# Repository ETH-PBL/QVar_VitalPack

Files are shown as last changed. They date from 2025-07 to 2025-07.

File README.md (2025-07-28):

# QVAR 6-Channel VitalCore Backpack

## A high-precision 6-channel physiological sensing interface board for VitalCore

Federico Villani, ETH Zurich PBL, IIS, 2023

- Board documentation: [QVAR VitalCore Backpack](hardware/Documentation/QVAR_VC_FULL_DOC.PDF)

## Overview

The QVAR 6-Channel VitalCore Backpack (QVar VitalPack) features six QVar channels, providing a flexible system for testing and implementing various combinations of electrode positions. Its compact size 19.5 mm×16.5 mm and light weight (1.12 g) make it ideal for integration into wearable devices.

### Key Features

- **6 Independent differential or single-ended Channels**: Can use either ST1VAFE3BX or LIS2DUXS12. Depending on the configuration, the channels can be used for differential or single-ended measurements.
- **VitalCore Interface**: Native compatibility with [VitalCore v1.3](https://github.com/ETH-PBL/VitalCore)
- **Compact Form Factor**: Space-efficient (19.5 mm×16.5 mm) design for portable and wearable applications
- **Signal Conditioning**: Integrated filtering and ESD protection
- **Power Management**: Possibility to use either DC-DC converters on VitalCore or LDOs.

## System Architecture

### Core Components

- **6x QVAR Channels**: The 6 QVAR channels (QA1, QA2, QB1, QB2, QC1, QC2) are attached to 3 different I2C buses (I2CA, I2CB, I2CC) with 2 channels per bus. The I2C interface can be changed to SPI with a minor modification of the PCB.
- **Power Management**: The QVAR channels can be powered either by VitalCore VCORE voltage rails or by VA0 rail (VitalCore LDO) and VD2 rail (VitalCore DC-DC converter) output (by changing position of jumpers JP_A and JP_D). The QVAR channels attached to I2CB bus have to be powered by VCORE as the I2CB bus is always on on VitalCore.
- **Analog connections**: Differential measurement channels can be attached to the 1.27mm pitch connectors on signal Q1 and Q2 (Q1 and Q2 are the differential inputs for Plus and Minus electrodes of the QVAR chip). Single-ended channels can be attached either to Q1 or to the UMC connectors on the back-side of the PCB. 
- **Operating Voltage**: Nominal 1.8V, Compatible with VitalCore power rails

## Repository Structure

```text
6QChan_vitalcore_backpack/
├── PCB/                           # PCB design files
│   ├── main.SchDoc               # Main schematic
│   ├── Interface.SchDoc          # Interface circuitry
│   ├── QVAR.SchDoc              # Channel schematic
│   ├── QVAR6_VC_Backpack.PcbDoc # PCB layout
│   └── Libraries/               # Component libraries
├── Documentation/               # Project documentation
│   ├── QVAR_VC_assembly.PDF    # Assembly documentation
│   ├── QVAR_VC_schematics.PDF  # Schematic documentation
│   ├── QVAR_VC_FULL_DOC.PDF    # Complete design documentation
│   ├── BOM/                     # Bill of materials
│   └── Manufacturing/          # Manufacturing files
│       ├── Gerber/             # Gerber files for fabrication
│       └── NC Drill/           # Drill files
├── Draftsman/                  # Assembly and manufacturing drawings
├── settings/                   # Project configuration
└── 6QChan_vitalcore_backpack.PrjPcb  # Altium Designer project
```

## Technical Specifications

### PCB Specifications

- **Layer Count**: 6-layer
- **PCB Thickness**: 0.8mm 
- **Via Technology**: through-hole vias, filled and plated (Via in pad)
- **Surface Finish**: ENIG

## Getting Started

### Prerequisites

- Altium Designer (recommended version 20.0 or later)

### Viewing the Design Files

1. **Open the project**:

   ```bash
   Open 6QChan_vitalcore_backpack.PrjPcb in Altium Designer
   ```

2. **Navigate the design**:
   - `main.SchDoc`: System-level connections and interfaces
   - `Interface.SchDoc`: VitalCore interface circuitry
   - `QVAR.SchDoc`: Individual channel design (hierarchical)
   - `QVAR6_VC_Backpack.PcbDoc`: Complete PCB layout

3. **Generate documentation**:
   - Use the OutJob file in `settings/QVAR_VC_Backpack.OutJob`
   - Generate PDFs, Gerber files, and BOMs as needed

## Manufacturing and Assembly

### PCB Fabrication

Complete manufacturing data is provided in the `hardware/Documentation/Manufacturing/` folder:

- **Gerber Files**: Complete layer stackup and routing
- **Drill Files**: Via and mounting hole specifications

## Documentation

- **Schematics**: Complete electrical schematics (`QVAR_VC_schematics.PDF`)
- **Assembly Guide**: Assembly instructions and component placement (`QVAR_VC_assembly.PDF`)
- **Complete Documentation**: Full design package (`QVAR_VC_FULL_DOC.PDF`)
- **Manufacturing Files**: Fabrication and assembly data packages

Access all documentation in the `Documentation/` folder.

## Usage

### Channel Configuration

- Each QVAR channel can be independently configured
- Proper grounding and shielding essential for biomedical applications
- Reference electrode connections for differential measurements

## Publications

If you use the QVAR 6-Channel VitalCore Backpack in an academic or industrial context, please cite the relevant publications:

```bibtex
TODO ADD PUBLICATION
```

## Contributing

This is an open hardware project. Contributions are welcome in the form of:

- **Design Improvements**: Enhanced performance and optimization
- **Documentation Enhancements**: Better assembly guides and specifications
- **Bug Reports**: Issue identification and resolution

## License

This project is released under an open hardware license:

- **Hardware Design Files**: Solderpad v0.51 (SHL-0.51) (see LICENSE)
- **Documentation**: Creative Commons Attribution 4.0 International License (CC-BY-4.0)

## Contact and Support

For technical questions or collaboration inquiries:

- **Primary Contact**: Federico Villani ([villanif@ethz.ch](mailto:villanif@ethz.ch))
- **Organization**: PBL, IIS - ETH Zurich

## Version History

- **Version 1.0**: Initial release 
  
---

## Limitation of Liability

In no event and under no legal theory, whether in tort (including negligence), contract, or otherwise, unless required by applicable law (such as deliberate and grossly negligent acts) or agreed to in writing, shall any Contributor be liable to You for damages, including any direct, indirect, special, incidental, or consequential damages of any character arising as a result of this License or out of the use or inability to use the Work (including but not limited to damages for loss of goodwill, work stoppage, computer failure or malfunction, or any and all other commercial damages or losses), even if such Contributor has been advised of the possibility of such damages.

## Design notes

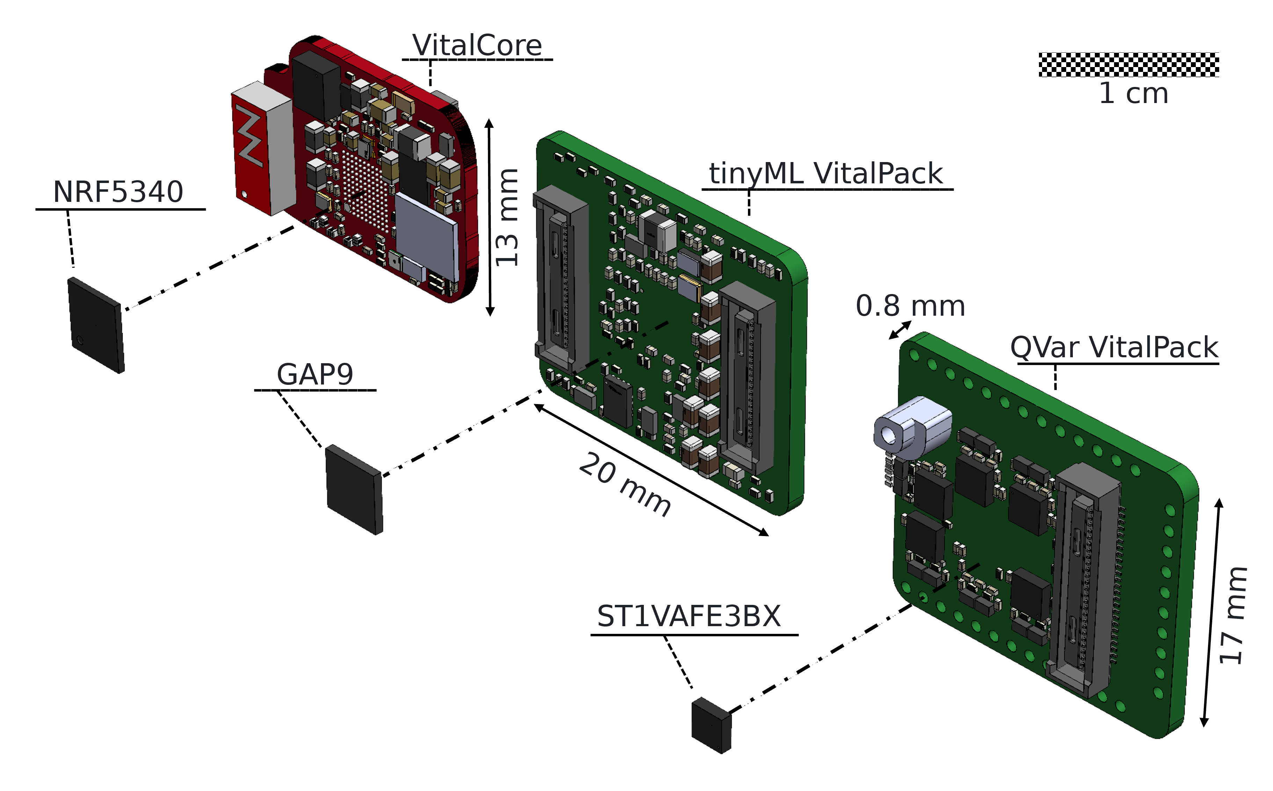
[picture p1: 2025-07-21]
assets/Electronics_3D.png

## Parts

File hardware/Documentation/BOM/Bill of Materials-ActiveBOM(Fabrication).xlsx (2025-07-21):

Line # | Name | Description | Designator | Footprint | LibRef | Supplier 1 | Supplier Part Number 1 | Quantity
1 | 0R | JMP 0201 3W | C1_QA1, C1_QA2, C1_QB1, C1_QB2, C1_QC1, C1_QC2, C2_QA1, C2_QA2, C2_QB1, C2_QB2, C2_QC1, C2_QC2 | RES_0201 | R_0201_0R_short_cap | Mouser | 667-ERJ-1GN0R00C | 12
1 | JMP | JMP 0201 3W | JP_A, JP_D | JMP_0201_3way | JMP_0201_3w | Mouser | 667-ERJ-1GN0R00C | 2
2 | 4.7k | R 4.7K 1% 50mW 0201 | R1_QA1, R1_QA2, R1_QB1, R1_QB2, R1_QC1, R1_QC2, R2_QA1, R2_QA2, R2_QB1, R2_QB2, R2_QC1, R2_QC2 | RES_0201 | R_0201_4.7K | Mouser | 667-ERJ-1GNF4701C | 12
3 | 100 nF | CAP CER 0.1UF 25V X5R 0201 | C5_QA1, C5_QA2, C5_QB1, C5_QB2, C5_QC1, C5_QC2, C6_QA1, C6_QA2, C6_QB1, C6_QB2, C6_QC1, C6_QC2 | CAP_0201 | CAP_0201_100n_10V | Mouser | 81-GRM33R6YA104ME14D | 12
4 | 110pF | CAP CER 110PF 50V C0G 0201 | CG1_QA1, CG1_QA2, CG1_QB1, CG1_QB2, CG1_QC1, CG1_QC2, CG2_QA1, CG2_QA2, CG2_QB1, CG2_QB2, CG2_QC1, CG2_QC2 | CAP_0201 | CAP_0201_110p_50V | Mouser | 81-GRM0335C1H111JA1D | 12
5 | 1µF | CAP CER 1UF 10V X6S | C4_QA1, C4_QA2, C4_QB1, C4_QB2, C4_QC1, C4_QC2, C7, C8, C9 | CAP_0201 | CAP_0201_1u_10V | Mouser | 81-GRM033C81A105ME5D | 9
6 | TPD1E01B04DPYRQ1 | TVS Diode (Bi-directional) | D1_QA1, D1_QA2, D1_QB1, D1_QB2, D1_QC1, D1_QC2, D2_QA1, D2_QA2, D2_QB1, D2_QB2, D2_QC1, D2_QC2 | TPD1E01B04DPYRQ1 | TPD1E01B04DPYRQ1 | Mouser | 595-TPD1E01B04DPYRQ1 | 12
7 | LIS2DUXS12TR | IC IMU QVAR | U1_QA1, U1_QA2, U1_QB1, U1_QB2, U1_QC1, U1_QC2 | QFN_DUXS12_STM-M | LIS2DUXS12TR | Mouser | 511-LIS2DUXS12TR | 6
8 | VitalCore Interface v1.0 | VitalCore Interface v1.0 | J1 | BACKPACK_INTERFACE_V1.0_2mm | BACKPACK_INTERFACE_V1.0 | Mouser | 798-DF40C2050DS04V51 | 1

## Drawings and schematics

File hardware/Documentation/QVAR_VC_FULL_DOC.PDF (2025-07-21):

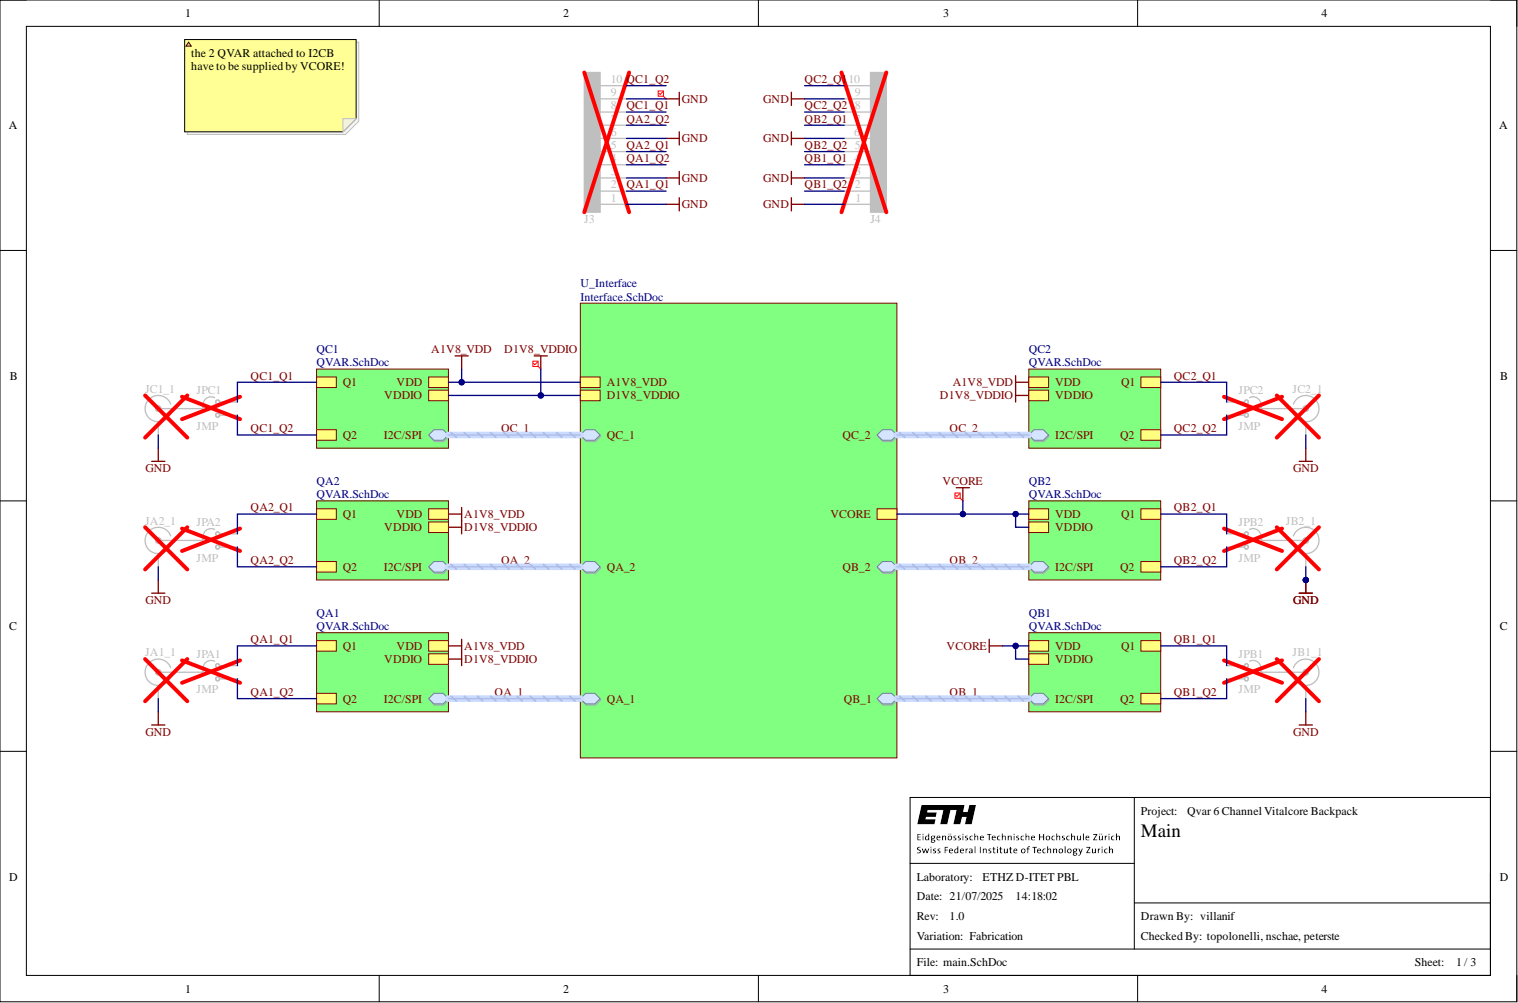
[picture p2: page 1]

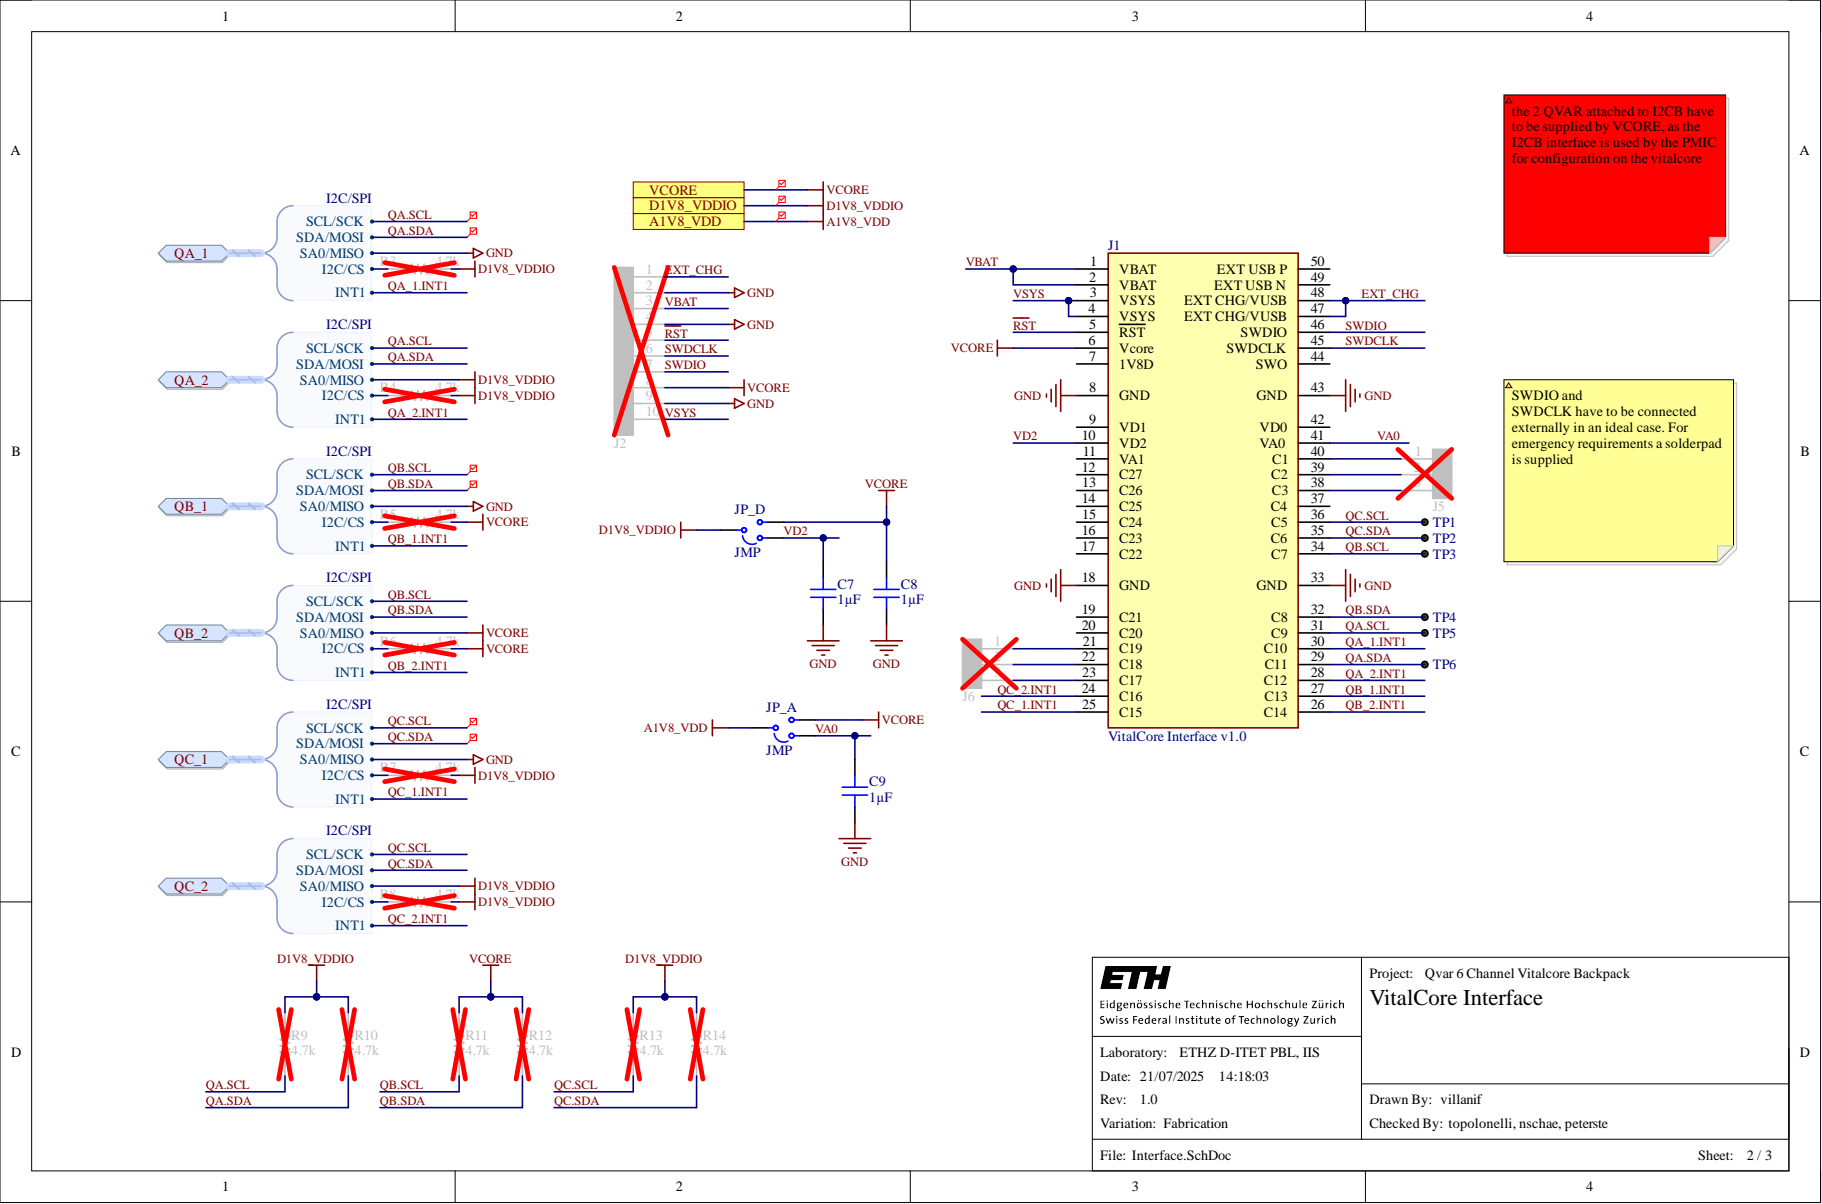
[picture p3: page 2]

QC.SCL QA.SDA QC.SDA

QB.SCL QB.SDA

QC.SCL QC.SDA

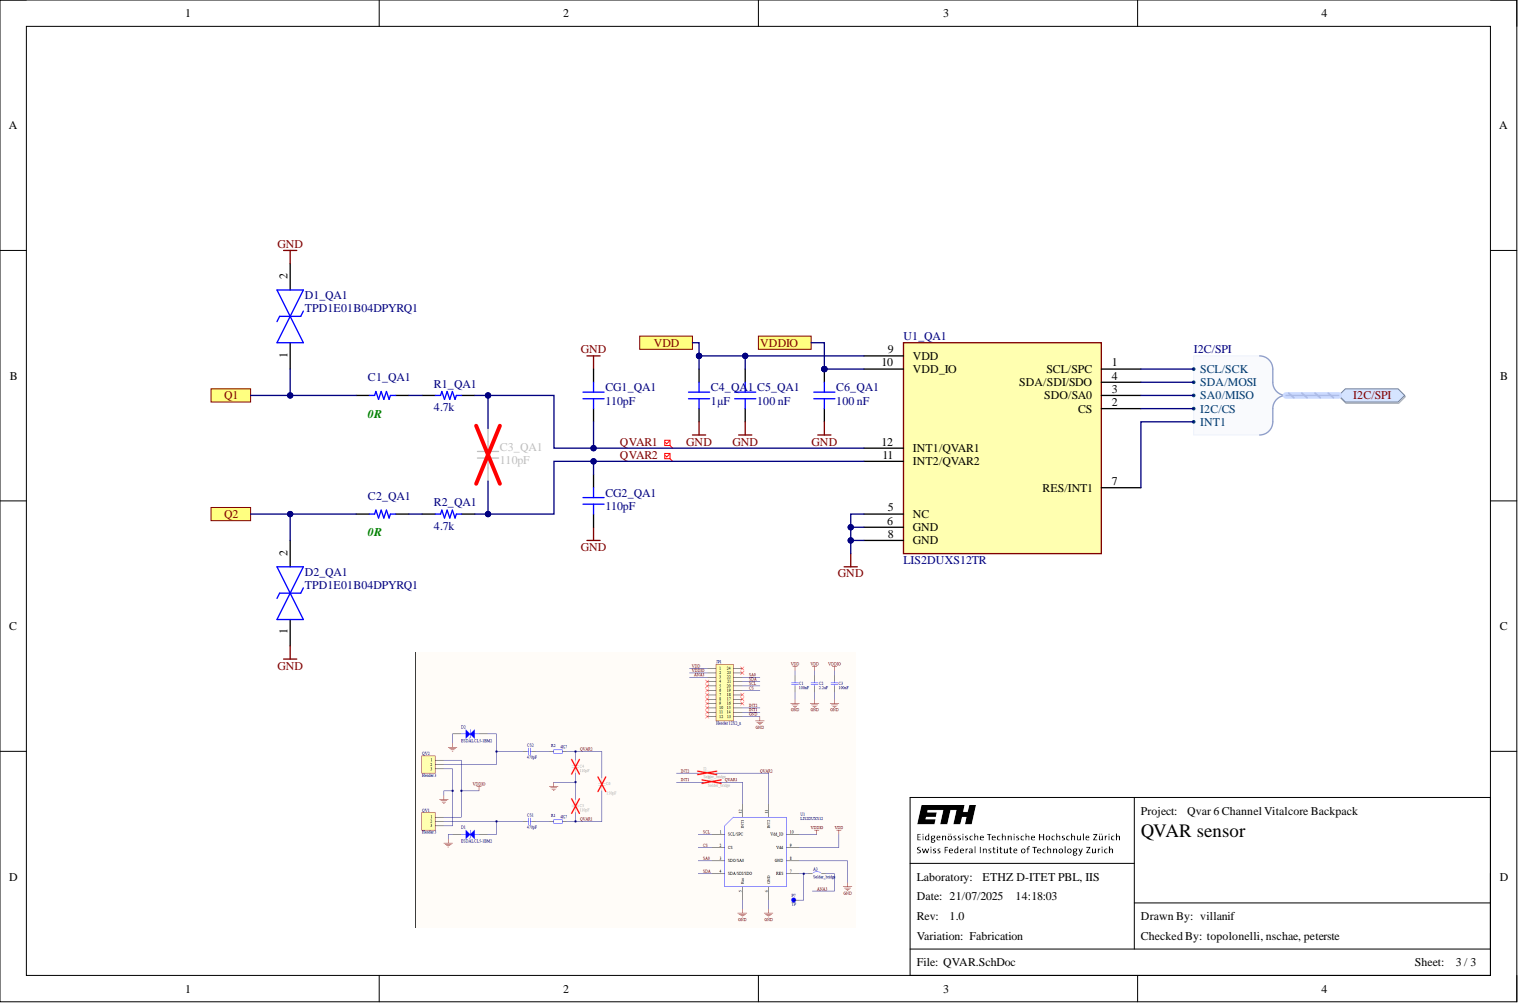
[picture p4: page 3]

VDD_IO 10

QVAR1 GND | GND | GND

NC 5
GND 6
GND 8

Project: Qvar 6 Channel Vitalcore Backpack
QVAR sensor

Laboratory: ETHZ D-ITET PBL, IIS
Date:
Rev:
Variation: Fabrication

Drawn By:
Checked By: topolonelli, nschae, peterste

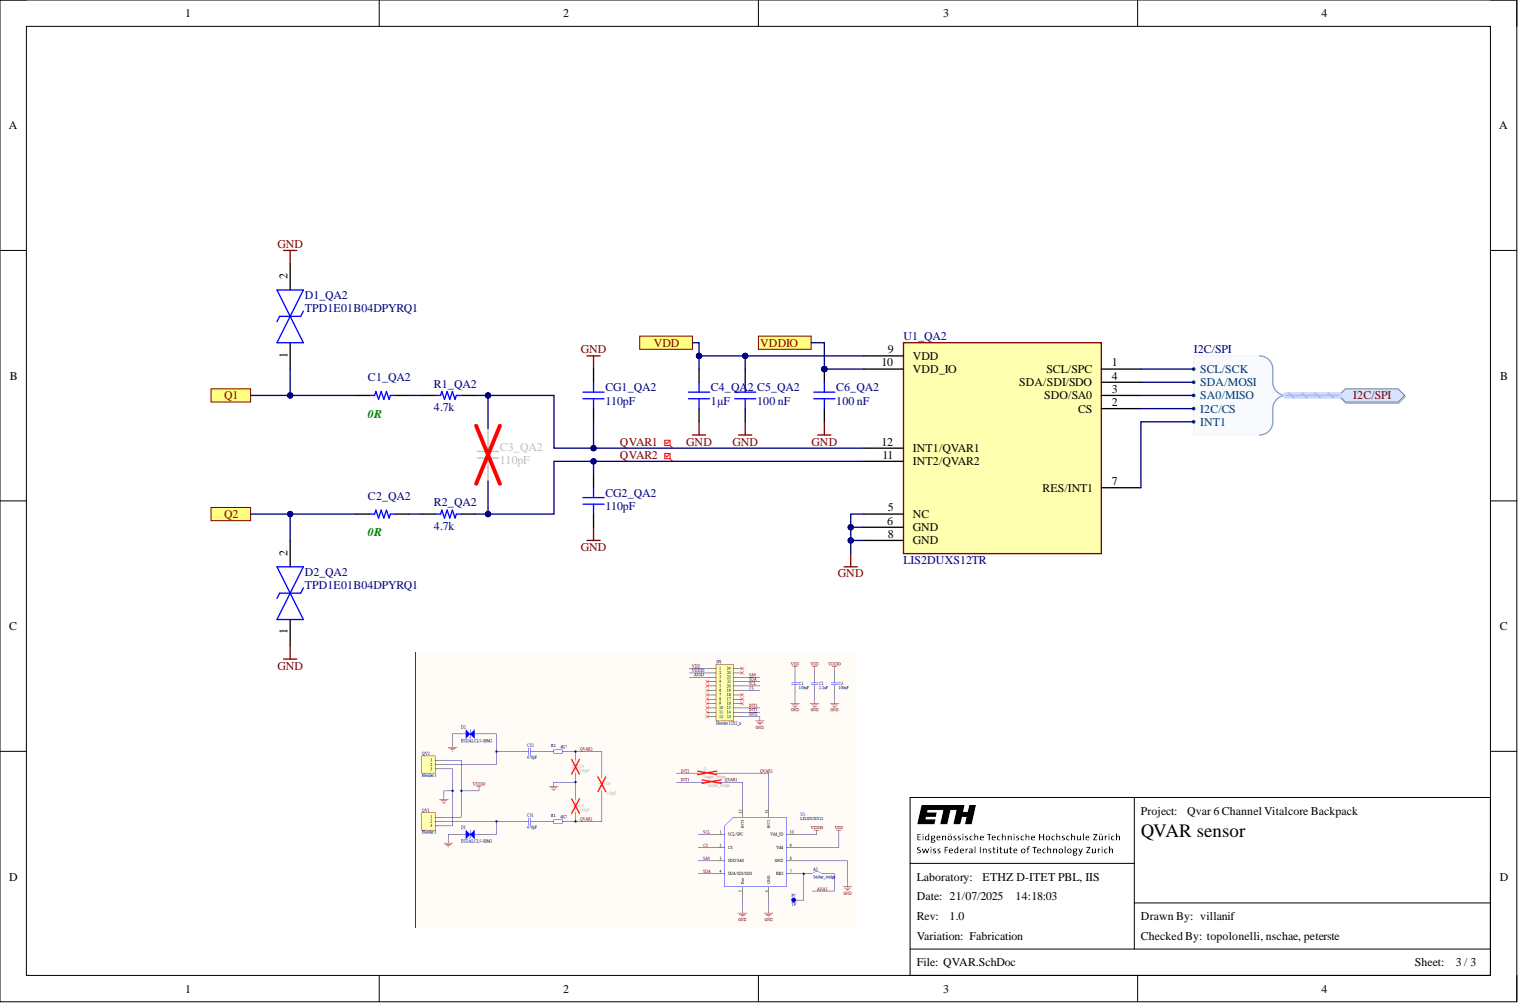
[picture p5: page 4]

VDD_IO 10

QVAR1 GND | GND | GND

NC 5
GND 6
GND 8

Project: Qvar 6 Channel Vitalcore Backpack
QVAR sensor

Laboratory: ETHZ D-ITET PBL, IIS
Date:
Rev:
Variation: Fabrication

Drawn By:
Checked By: topolonelli, nschae, peterste

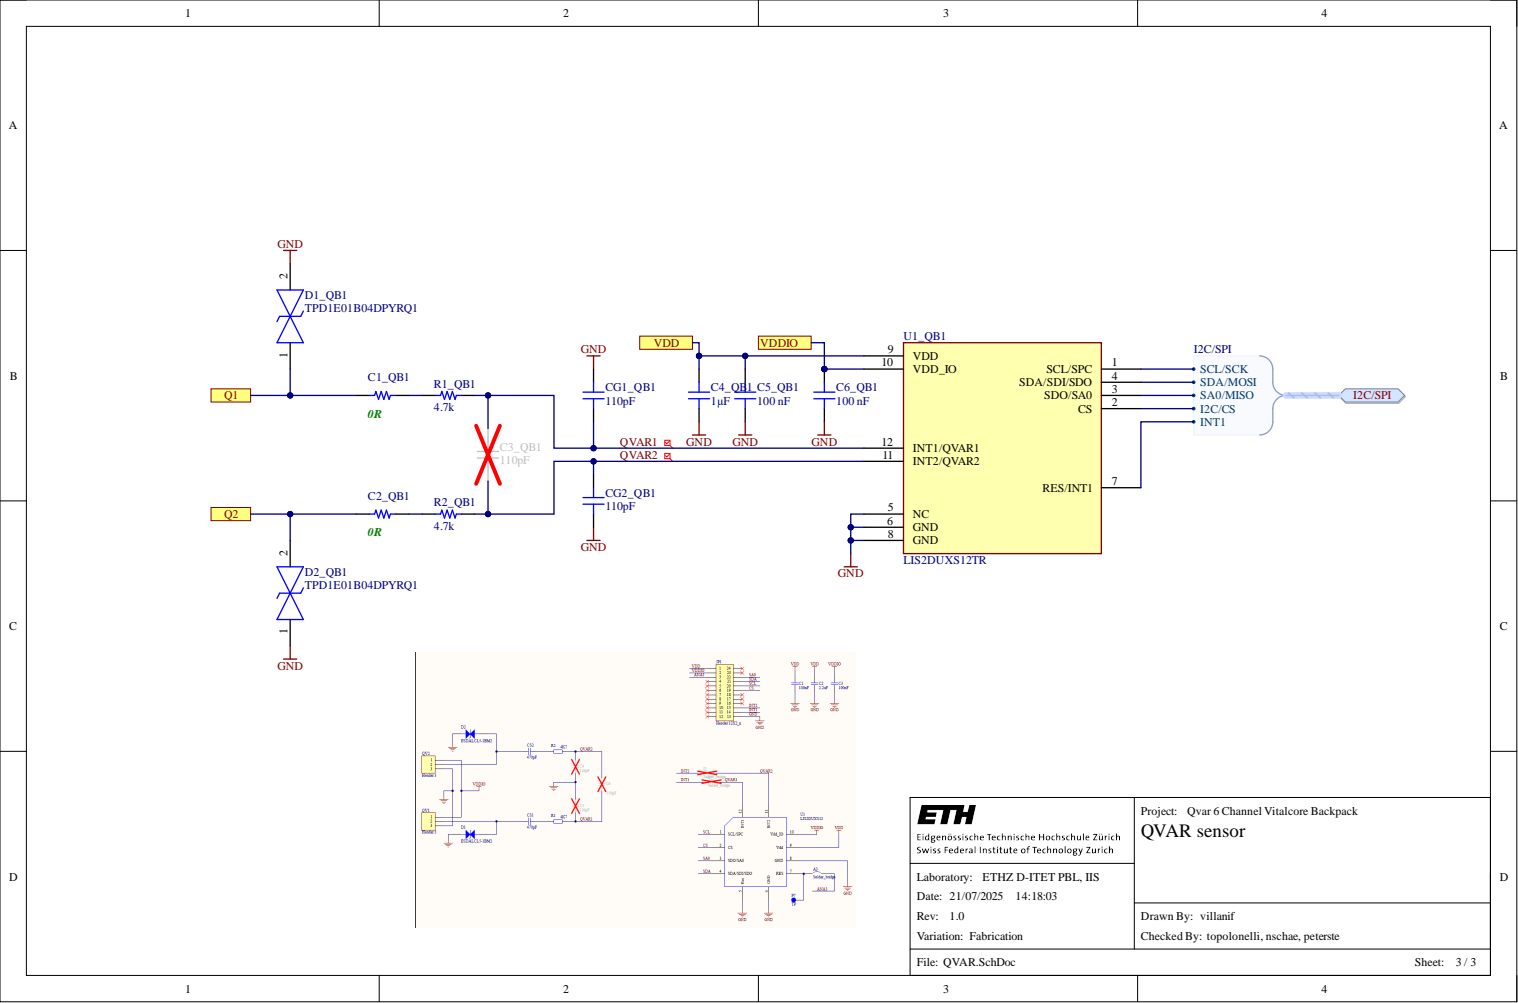
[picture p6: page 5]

VDD_IO 10

QVAR1 GND | GND | GND

NC 5
GND 6
GND 8

Project: Qvar 6 Channel Vitalcore Backpack
QVAR sensor

Laboratory: ETHZ D-ITET PBL, IIS
Date:
Rev:
Variation: Fabrication

Drawn By:
Checked By: topolonelli, nschae, peterste

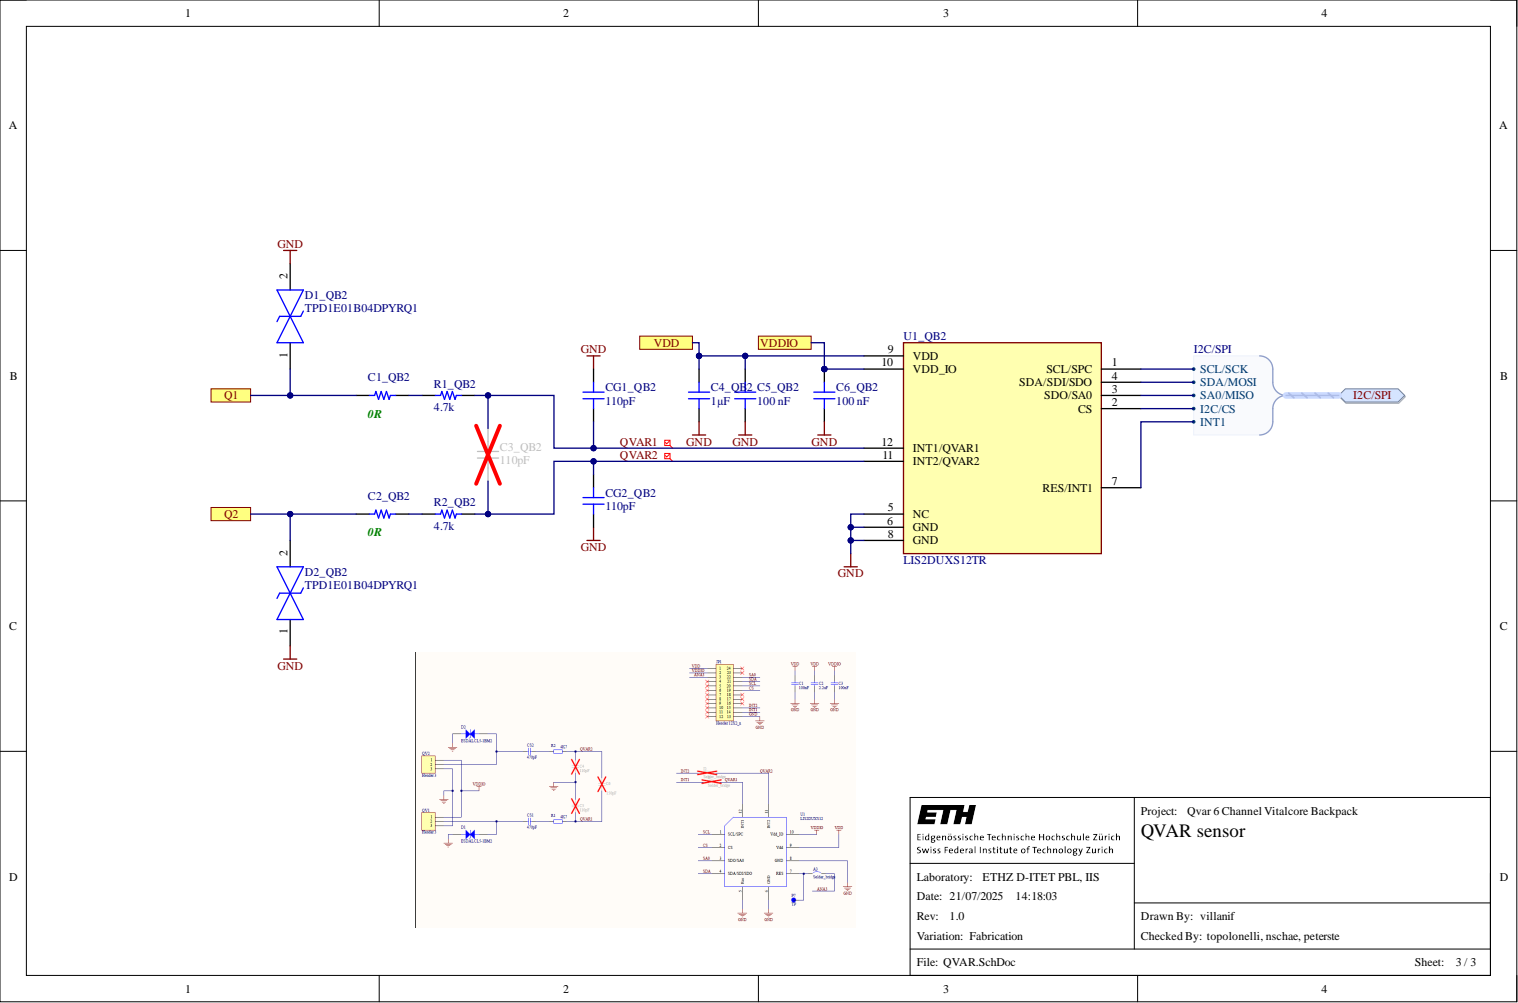
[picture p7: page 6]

VDD_IO 10

QVAR1 GND | GND | GND

NC 5
GND 6
GND 8

Project: Qvar 6 Channel Vitalcore Backpack
QVAR sensor

Laboratory: ETHZ D-ITET PBL, IIS
Date:
Rev:
Variation: Fabrication

Drawn By:
Checked By: topolonelli, nschae, peterste

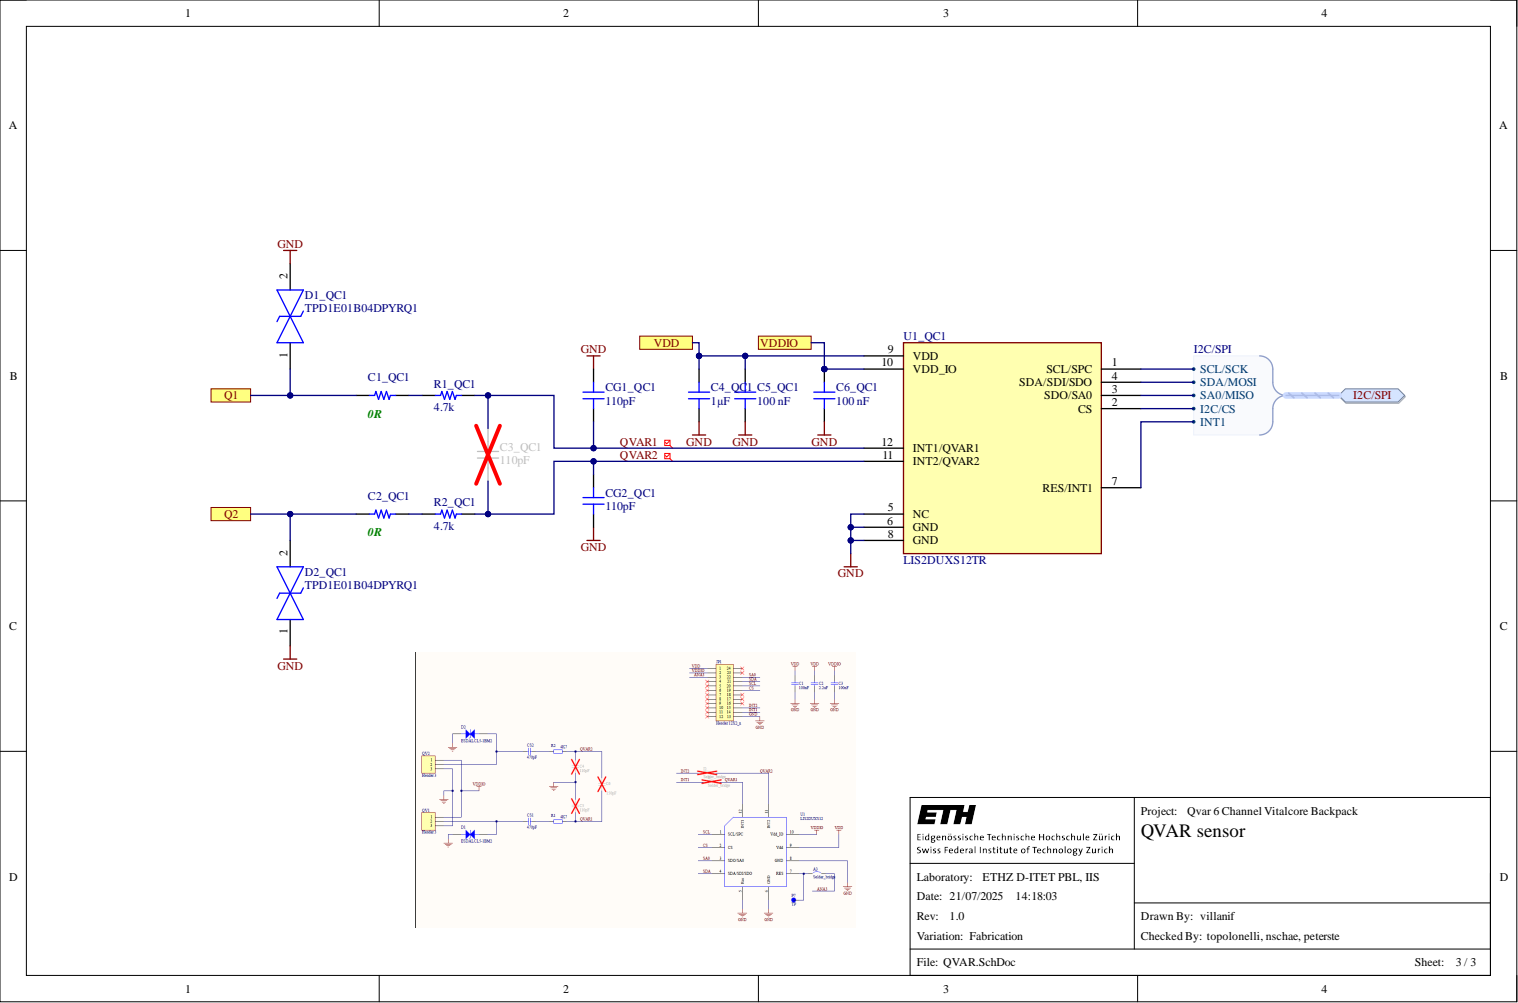
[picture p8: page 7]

VDD_IO 10

QVAR1 GND | GND | GND

NC 5
GND 6
GND 8

Project: Qvar 6 Channel Vitalcore Backpack
QVAR sensor

Laboratory: ETHZ D-ITET PBL, IIS
Date:
Rev:
Variation: Fabrication

Drawn By:
Checked By: topolonelli, nschae, peterste

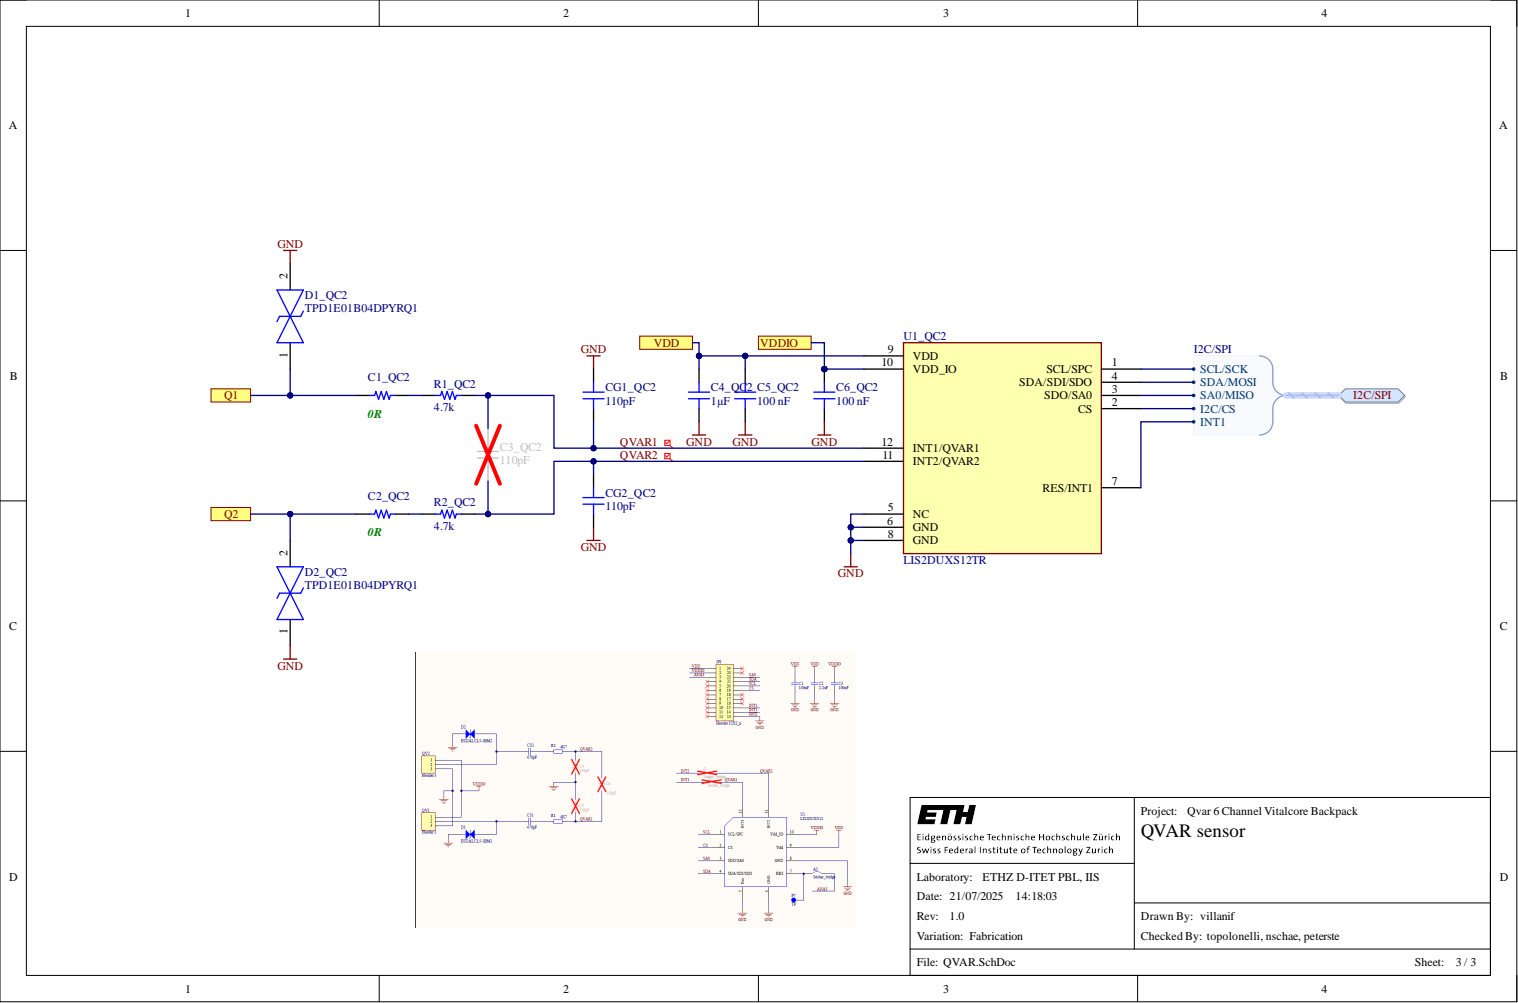
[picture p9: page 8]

VDD_IO 10

QVAR1 GND | GND | GND

NC 5
GND 6
GND 8

Project: Qvar 6 Channel Vitalcore Backpack
QVAR sensor

Laboratory: ETHZ D-ITET PBL, IIS
Date:
Rev:
Variation: Fabrication

Drawn By:
Checked By: topolonelli, nschae, peterste

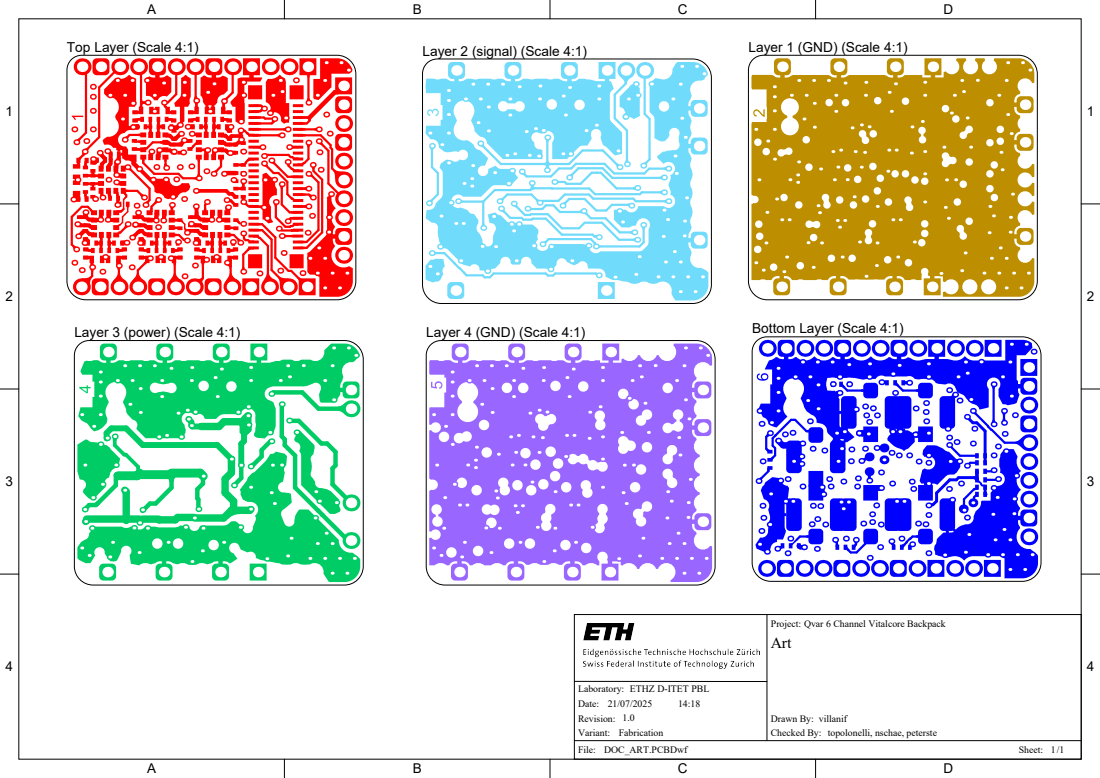
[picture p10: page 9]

Qvar 6 Channel Vitalcore Backpack

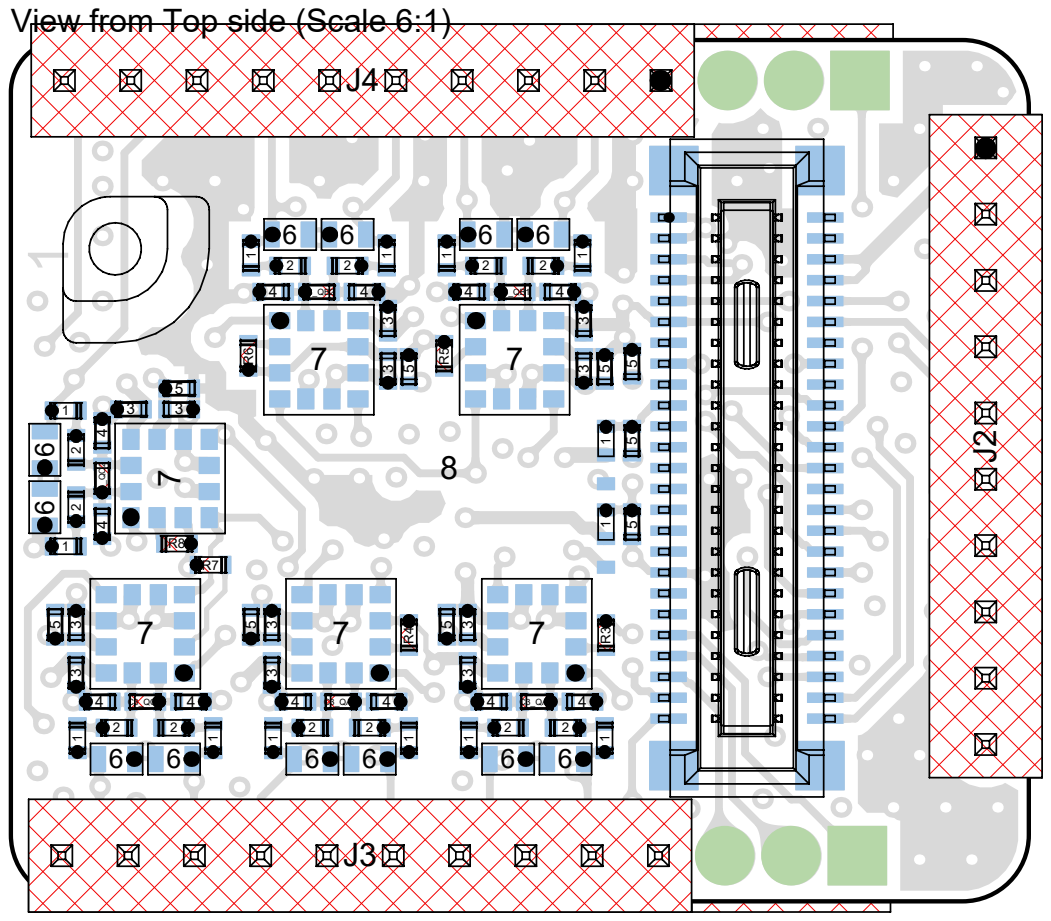
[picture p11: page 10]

View from Top side (Scale 6:1)

Qvar 6 Channel Vitalcore Backpack

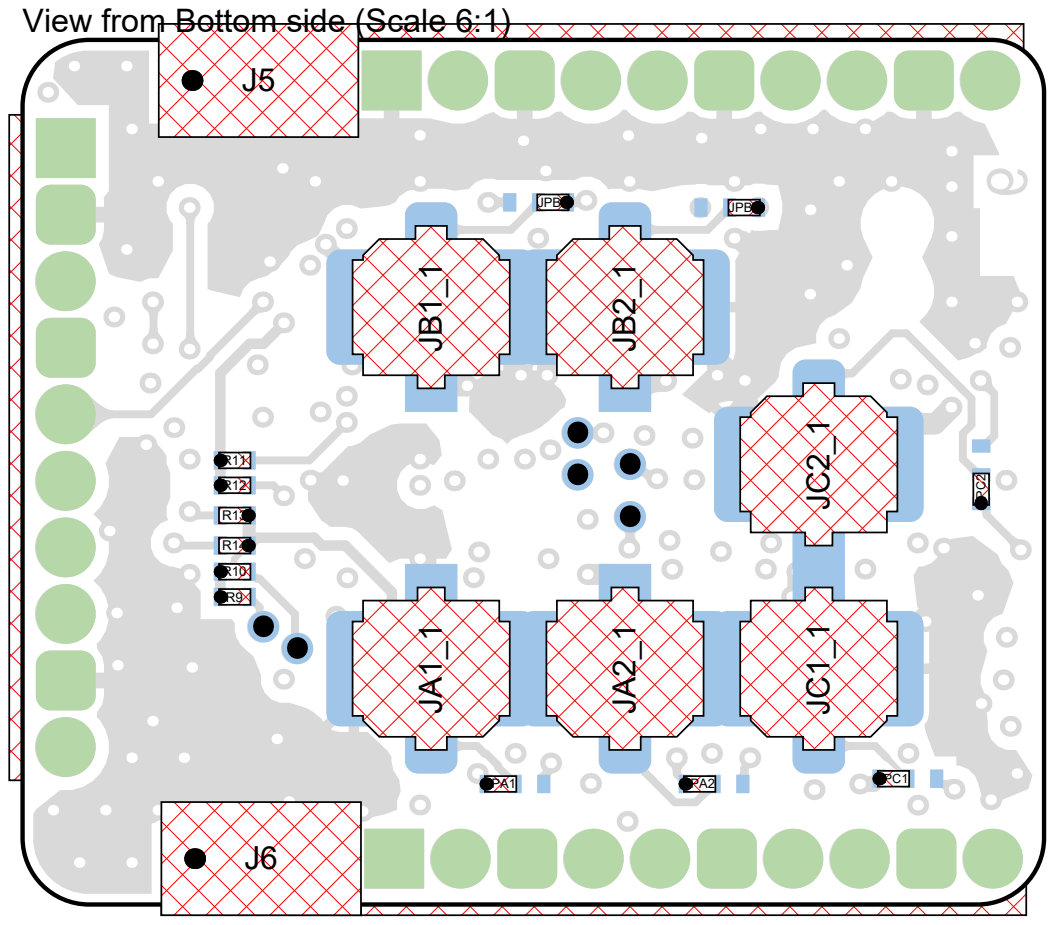
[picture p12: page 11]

View from Bottom side (Scale 6:1)

Qvar 6 Channel Vitalcore Backpack

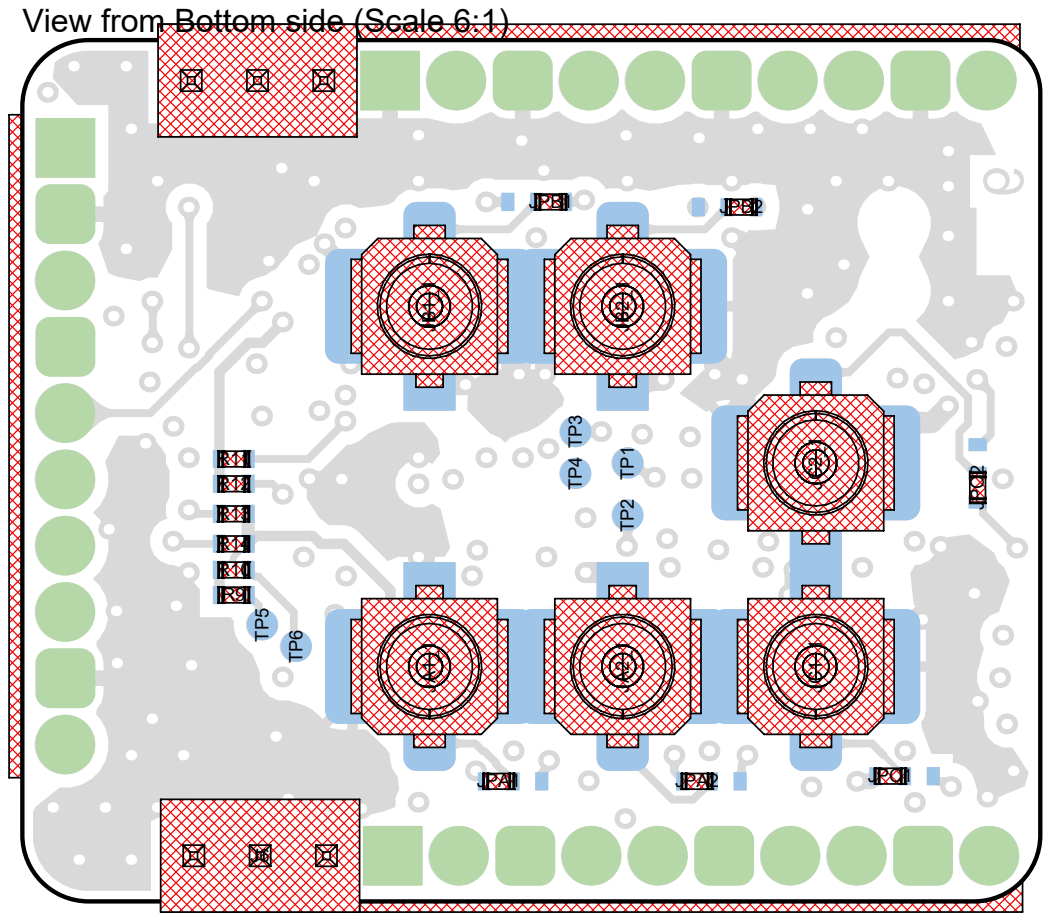
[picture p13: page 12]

View from Bottom side (Scale 6:1)

Qvar 6 Channel Vitalcore Backpack


View from Top side (Scale 6:1)

Qvar 6 Channel Vitalcore Backpack


Drill Drawing View (Scale 8:1)

Qvar 6 Channel Vitalcore Backpack

Symbol | Count | Hole Size | Plated | Drill Layer Pair

193 | 0.20mm | Plated | Top Layer - Bottom Layer
36 | 0.71mm | Plated | Top Layer - Bottom Layer

0.90mm | Non-Plated | Top Layer - Bottom Layer

231 Total


NOTES:
- Via in pad
- 0.8mm Board: Use JLCPCB standard stackup
- ENIG finish.

Qvar 6 Channel Vitalcore Backpack


Line # | Designator | Name | Quantity | Design Item Id | Manufacturer | Manufacturer Part Number
1 | C1_QA1, C1_QA2, C1_QB1, C1_QB2, C1_QC1, C1_QC2, C2_QA1, C2_QA2, C2_QB1, C2_QB2, C2_QC1, C2_QC2 | 0R | 12 | R_0201_0R_short_cap | Panasonic | ERJ-1GN0R00C

1 | JP_A, JP_D | JMP | 2 | JMP_0201_3w | Panasonic | ERJ-1GN0R00C
2 | R1_QA1, R1_QA2, R1_QB1, R1_QB2, R1_QC1, R1_QC2, R2_QA1, R2_QA2, R2_QB1, R2_QB2, R2_QC1, R2_QC2 | 4.7k | 12 | R_0201_4.7K | Panasonic | ERJ-1GNF4701C

3 | C5_QA1, C5_QA2, C5_QB1, C5_QB2, C5_QC1, C5_QC2, C6_QA1, C6_QA2, C6_QB1, C6_QB2, C6_QC1, C6_QC2 | 100 nF | 12 | CAP_0201_100n_10V | Murata | GRM033R6YA104ME14D

4 | CG1_QA1, CG1_QA2, CG1_QB1, CG1_QB2, CG1_QC1, CG1_QC2, CG2_QA1, CG2_QA2, CG2_QB1, CG2_QB2, CG2_QC1, CG2_QC2 | 110pF | 12 | CAP_0201_110p_50V | Murata | GRM0335C1H111JA01D

5 | C4_QA1, C4_QA2, C4_QB1, C4_QB2, C4_QC1, C4_QC2, C7, C8, C9 | 1µF | 9 | CAP_0201_1u_10V | Murata | GRM033C81A105ME05D

6 | D1_QA1, D1_QA2, D1_QB1, D1_QB2, D1_QC1, D1_QC2, D2_QA1, D2_QA2, D2_QB1, D2_QB2, D2_QC1, D2_QC2 | TPD1E01B04DPYRQ1 | 12 | TPD1E01B04DPYRQ1 | Texas Instruments | TPD1E01B04DPYRQ1

7 | U1_QA1, U1_QA2, U1_QB1, U1_QB2, U1_QC1, U1_QC2 | LIS2DUXS12TR | 6 | LIS2DUXS12TR | STMicroelectronics | LIS2DUXS12TR

8 | J1 | VitalCore Interface v1.0 | 1 | BACKPACK_INTERFACE_ V1.0 | Hirose | DF40C(2.0)-50DS-0.4V(51)

Qvar 6 Channel Vitalcore Backpack


View from Front side (Scale 3.528:1)

Qvar 6 Channel Vitalcore Backpack

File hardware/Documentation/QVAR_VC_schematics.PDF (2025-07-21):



QC.SCL QA.SDA QC.SDA

QB.SCL QB.SDA

QC.SCL QC.SDA


VDD_IO 10

QVAR1 GND | GND | GND

NC 5
GND 6
GND 8

Project: Qvar 6 Channel Vitalcore Backpack
QVAR sensor

Laboratory: ETHZ D-ITET PBL, IIS
Date:
Rev:
Variation: Fabrication

Drawn By:
Checked By: topolonelli, nschae, peterste


VDD_IO 10

QVAR1 GND | GND | GND

NC 5
GND 6
GND 8

Project: Qvar 6 Channel Vitalcore Backpack
QVAR sensor

Laboratory: ETHZ D-ITET PBL, IIS
Date:
Rev:


VDD_IO 10

QVAR1 GND | GND | GND

NC 5
GND 6
GND 8

Project: Qvar 6 Channel Vitalcore Backpack
QVAR sensor

Laboratory: ETHZ D-ITET PBL, IIS
Date:
Rev:


VDD_IO 10

QVAR1 GND | GND | GND

NC 5
GND 6
GND 8

Project: Qvar 6 Channel Vitalcore Backpack
QVAR sensor

Laboratory: ETHZ D-ITET PBL, IIS
Date:
Rev:


VDD_IO 10

QVAR1 GND | GND | GND

NC 5
GND 6
GND 8

Project: Qvar 6 Channel Vitalcore Backpack
QVAR sensor

Laboratory: ETHZ D-ITET PBL, IIS
Date:
Rev:


VDD_IO 10

QVAR1 GND | GND | GND

NC 5
GND 6
GND 8

Project: Qvar 6 Channel Vitalcore Backpack
QVAR sensor

Laboratory: ETHZ D-ITET PBL, IIS
Date:
Rev:

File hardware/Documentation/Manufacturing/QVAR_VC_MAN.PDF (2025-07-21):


Drill Drawing View (Scale 8:1)

Qvar 6 Channel Vitalcore Backpack

Symbol | Count | Hole Size | Plated | Drill Layer Pair

193 | 0.20mm | Plated | Top Layer - Bottom Layer
36 | 0.71mm | Plated | Top Layer - Bottom Layer
2 | 0.90mm | Non-Plated | Top Layer - Bottom Layer
231 Total


NOTES:
- Via in pad
- 0.8mm Board: Use JLCPCB standard stackup
- ENIG finish.

Qvar 6 Channel Vitalcore Backpack

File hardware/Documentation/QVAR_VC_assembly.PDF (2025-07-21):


View from Top side (Scale 6:1)

Qvar 6 Channel Vitalcore Backpack


View from Bottom side (Scale 6:1)

Qvar 6 Channel Vitalcore Backpack

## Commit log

2023-11-13 refinements for production, checklist missing
    [6QChan_vitalcore_backpack.PrjPcb, Interface.SchDoc, QVAR.SchDoc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]
2023-11-17 Sent for production V1
    [6QChan_vitalcore_backpack.PrjPcb, Bill of Materials-ActiveBOM(Fabrication).xlsx, Bill of Materials-ActiveBOM.xlsx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]
2025-07-21 Initial cleanup for publication branch
    [Bill of Materials-ActiveBOM(Fabrication).xlsx, Bill of Materials-ActiveBOM.xlsx, FTS-103-01-L-S.stp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]
2025-07-21 add output job files
    [6QChan_vitalcore_backpack.PrjPcb, Bill of Materials-ActiveBOM(Fabrication).xlsx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]
2025-07-21 Reformatted repository
    [6QChan_vitalcore_backpack.PrjPcb, Bill of Materials-ActiveBOM(Fabrication).xlsx, Interface.SchDoc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]
